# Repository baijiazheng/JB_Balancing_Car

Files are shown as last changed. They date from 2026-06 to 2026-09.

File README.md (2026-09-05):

# JB_Balancing_Car

> A two-wheeled self-balancing robot built around the self-designed JB_board.

## 📖 Project Overview

**JB_Balancing_Car** is a two-wheeled self-balancing robot developed from scratch.

The project combines:

- IMU
- DC geared motors
- Quadrature encoders
- Motor driver
- Real-time control
- PD control
- Velocity-loop architecture
- Timer-based task scheduling
- A self-designed control board — **JB_board**

The project was developed as a practical study of the complete robotics control chain:

```text
Sensor
  ↓
State Estimation
  ↓
Control
  ↓
Motor Output
  ↓
Mechanical Motion
  ↓
Sensor Feedback
```

---

## 🎯 Project Goals

The main objectives were:

- Build a two-wheeled self-balancing robot.
- Design and use a custom control board.
- Integrate an MPU6050 IMU.
- Control two DC motors.
- Acquire encoder feedback.
- Implement a real-time upright controller.
- Explore a cascaded velocity-control architecture.
- Practice hardware/software co-design.
- Develop systematic hardware debugging skills.

---

## 🧩 System Architecture

```text
                 ┌──────────────┐
                 │   MPU6050    │
                 │     IMU      │
                 └──────┬───────┘
                        │
                        ▼
                 ┌──────────────┐
                 │ State        │
                 │ Estimation   │
                 └──────┬───────┘
                        │
                        ▼
                 ┌──────────────┐
                 │ Upright PD   │
                 │ Controller   │
                 └──────┬───────┘
                        │
                        ▼
                 ┌──────────────┐
                 │ Motor Driver │
                 └──────┬───────┘
                        │
                 ┌──────┴──────┐
                 ▼             ▼
              Motor L       Motor R
                 │             │
                 ▼             ▼
             Encoder L     Encoder R
                 │             │
                 └──────┬──────┘
                        ▼
                    Feedback
```

---

## 🔧 Hardware

### Main Components

- **JB_board** — custom control board
- MPU6050 — 6-axis IMU
- Two DC geared motors
- Quadrature encoders — AB-phase feedback
- Motor driver
- 2S LiPo battery
- Two-wheel mechanical chassis

---

## 💻 Software Architecture

The control system uses periodic execution based on hardware timers.

The basic structure is:

```text
Timer
  ↓
Interrupt
  ↓
Set Control Flag
  ↓
Main Loop
  ↓
Read Sensors
  ↓
Calculate Control
  ↓
Output Motor PWM
```

The timer interrupt is kept lightweight, while the main loop performs sensor processing and control calculations.

---

## ⚙️ Upright Control

The primary controller is a PD controller.

```text
Angle Error
     ↓
     P
     +
Angular Velocity
     ↓
     D
     ↓
 Motor PWM
```

The proportional term provides the main restoring action.

The derivative term provides damping and helps reduce oscillation.

---

## 🔄 Velocity Loop

The project was extended toward a cascaded control architecture:

```text
Target Speed
     ↓
Velocity PI Controller
     ↓
Target Angle
     ↓
Upright PD Controller
     ↓
Motor PWM
```

This separates two control objectives:

- **Upright loop** — keeps the robot balanced.
- **Velocity loop** — controls the robot's movement speed.

---

## ⏱️ Real-Time Control

Timer-based scheduling is used to create periodic control tasks.

The basic concept is:

```text
Hardware Timer
      ↓
ISR
      ↓
Flag
      ↓
Main Loop
      ↓
Control Task
```

ISR (中断服务程序) is used to respond to timer events and set the corresponding flag.

The main loop then performs the actual control work.

This approach avoids placing large amounts of computation inside the interrupt routine.

---

## 🔄 Encoder Development

The encoder subsystem became an important part of the project.

The project experimented with:

- External interrupt-based detection
- Timer-based polling
- A/B phase direction detection
- Encoder count accumulation
- Speed feedback

The basic quadrature encoder concept is:

```text
A Phase
   +
B Phase
   ↓
Pulse + Direction
```

The system detects an A-phase transition and checks the B-phase state to determine the direction of rotation.

---

## ⚠️ Hardware Debugging

One of the most important problems encountered during development was encoder instability.

The encoder behaved normally when the motors were not driven.

After the motors were driven, the encoder signals became unreliable.

The debugging process involved:

- Pull-up resistors
- Filter capacitors
- Signal wiring
- Encoder input levels
- Timer polling
- Interrupt detection
- PCB traces
- Motor current
- Electromagnetic interference

The final investigation showed that the physical PCB layout was an important part of the problem.

Motor-related current switching introduced interference into nearby encoder signal traces.

This led to an important engineering lesson:

> **A digital signal is still a physical electrical signal.**

The MCU does not see an abstract `HIGH` or `LOW`.

It sees a real voltage waveform affected by:

- Current switching
- Ground noise
- Electromagnetic coupling
- PCB routing
- Signal integrity
- Wiring

---

## 🧠 Major Engineering Lessons

### 1. Software cannot always fix a hardware problem

If the physical signal is already corrupted, changing the decoding algorithm may not solve the root cause.

```text
Bad Physical Signal
        ↓
Better Algorithm
        ↓
Still Unreliable
```

The debugging process should therefore move from:

```text
Physical Layer
      ↓
Electrical Signal
      ↓
MCU Input
      ↓
Software
```

---

### 2. High-current and low-level signals require different treatment

The motor power path and encoder/IMU signal path have very different electrical characteristics.

```text
Motor
 ↓
Large Current
 ↓
Fast Switching
```

while:

```text
Encoder / IMU
 ↓
Low-level Signal
 ↓
Sensitive to Noise
```

PCB routing, grounding, filtering, and signal separation therefore become critical.

---

### 3. Change one variable at a time

The project also reinforced a fundamental debugging rule:

> **Change one variable at a time.**

Examples include:

- Removing motor drive
- Changing encoder connections
- Swapping left/right channels
- Testing different pull-up resistors
- Adding filtering
- Cutting PCB traces
- Using external wires
- Comparing different decoding methods

This makes it possible to distinguish correlation from causation.

---

## 🏁 Project Result

The V1 system achieved the following milestones:

- Custom control board designed and used
- MPU6050 integration
- Motor control
- Upright PD control
- Timer-based control architecture
- Encoder signal acquisition experiments
- Initial velocity-loop architecture
- Real-world hardware debugging

The V1 PCB design also exposed hardware limitations that prevented the encoder subsystem from reaching the reliability required for further closed-loop development.

Instead of endlessly modifying V1, the hardware was therefore frozen and the lessons were carried forward into the next board revision.

---

## 🛠️ JB_board V2 Direction

The next hardware revision will focus on electrical reliability.

Planned improvements include:

### Power Layout

Separate:

```text
High-current motor power
```

from:

```text
Low-level sensor signals
```

### Signal Routing

Improve:

- Encoder routing
- Grounding
- Signal separation
- Filtering
- Pull-up configuration

### Hardware Reliability

The next revision will prioritize:

```text
Reliable Electrical Signal
        ↓
Reliable Sensor Data
        ↓
Reliable Control
```

before further control optimization.

---

## 📚 What This Project Represents

JB_Balancing_Car represents my first serious attempt to understand a robot as a complete system.

```text
Mechanical System
       +
Electrical System
       +
Embedded Firmware
       +
Control Theory
       +
Real-Time System
       +
Debugging
```

The most valuable result of V1 was not simply whether the robot could stand.

It was learning how failures propagate through a real robotic system and how to trace those failures back to their physical root cause.

---

## 🚀 Future Development

Future development will continue through a new hardware revision:

```text
JB_board V2
      ↓
Reliable Encoder
      ↓
Velocity Loop
      ↓
Cascaded Control
      ↓
Parameter Tuning
      ↓
More Advanced Robot Control
```

The V1 repository will remain as a record of the first hardware and control iteration.

---

## 📌 Project Status

**V1.0 — Frozen**

The V1 hardware is considered a completed experimental iteration.

Future development will be transferred to the next hardware revision.

---

## 👤 Author

**JB**

Robotics / Embedded Systems / Control

GitHub: `baijiazheng`

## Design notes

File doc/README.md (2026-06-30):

# JB_Balancing_Car
This is a two-wheeled self-balancing car that operates on a self-designed board——JB_board.

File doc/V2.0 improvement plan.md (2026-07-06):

电源部分

★★★★★

AMS1117更换为Buck DC-DC。

提高效率。

提升抗瞬态能力。

电机驱动

★★★★☆

继续使用TB6612。

若以后升级电机：

建议使用：

DRV8874
DRV8876
BTS7960
电源保护

★★★★★

取消0805小规格PPTC。

改用：

Mini Blade汽车保险丝。

PCB布局

★★★★☆

进一步分离：

动力区

控制区

减小地回流影响。

调试接口

★★★★★

所有重要信号全部增加Test Point。

电源储能

★★★★☆

TB6612 VM旁增加：

1000µF以上低ESR电解。

提升启动瞬态能力。

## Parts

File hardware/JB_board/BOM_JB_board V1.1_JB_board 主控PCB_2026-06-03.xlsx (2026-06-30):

No. | Quantity | Comment | Designator | Footprint | Value | Manufacturer Part | Manufacturer | Supplier Part | Supplier
1 | 1 | 470uF | C1 | CAP-TH_BD6.3-P2.50-D0.5-FD | 470uF | GR1C471M0611 | ROQANG(容强) | C2873966 | LCSC
2 | 15 | 100nF | C2,C5,C6,C7,C8,C9,C10,C11,C12,C13,C14,C15,C16,C18,C20 | C0805 | 100nF | FCC0805B104K500DT | FOJAN(富捷) | C5137467 | LCSC
3 | 2 | 10uF | C3,C17 | C0805 | 10uF | CGA0805X5R106K250MT | HRE(芯声) | C6119887 | LCSC
4 | 1 | 22uF | C4 | CASE-A_3216 | 22uF | TAJA226K010RNJ | Kyocera AVX | C11366 | LCSC
5 | 1 | SH-XH2.54-2PWZ | CN1 | CONN-TH_SH-XH2.54-2PWZ |  | SH-XH2.54-2PWZ | SHOU HAN(首韩) | C42372642 | LCSC
6 | 2 | HX-PH2.0-4PZZ | CN2,CN3 | CONN-TH_HX-PH2.0-4PZZ |  | HX-PH2.0-4PZZ | hanxia(韩下) | C48641619 | LCSC
7 | 2 | HX002069 | CN4,CN5 | CONN-TH_2P-P2.00-H |  | HX002069 | hanxia(韩下) | C22387095 | LCSC
8 | 1 | SMBJ5.0A | D1 | SMB_L4.3-W3.6-LS5.3-RD |  | SMBJ5.0A | MSKSEMI(美森科) | C5331094 | LCSC
9 | 1 | SMD0805-100-12 | F1 | R0805 |  | SMD0805-100-12 | R+O(宏嘉诚) | C46640991 | LCSC
10 | 1 | PM254V-11-06-H85 | H1 | HDR-TH_6P-P2.54-V-F |  | PM254V-11-06-H85 | XFCN(兴飞) | C2832269 | LCSC
11 | 4 | HC-PM254-5.0H-1x4PZ-02A | H2,H3,H4,H5 | HDR-TH_4P-P2.54-V-F |  | HC-PM254-5.0H-1x4PZ-02A | HC(虹成电子) | C42163122 | LCSC
12 | 8 | PZ254V-11-02P | H6,H7,H8,H9,H10,H11,H12,H13 | HDR-TH_2P-P2.54-V-M |  | PZ254V-11-02P | XFCN(兴飞) | C492401 | LCSC
13 | 1 | XL-2012SURC | LED1 | LED0805-RD_RED |  | XL-2012SURC | XINGLIGHT(成兴光) | C965812 | LCSC
14 | 2 | 2kΩ | R1,R5 | R0805 | 2kΩ | FRC0805J202 TS | FOJAN(富捷) | C2907315 | LCSC
15 | 7 | 10kΩ | R2,R3,R20,R21,R26,R28,R30 | R0805 | 10kΩ | FRC0805J103TS | FOJAN(富捷) | C2930231 | LCSC
16 | 1 | 1kΩ | R4 | R0805 | 1kΩ | FRC0805J102 TS | FOJAN(富捷) | C2907295 | LCSC
17 | 8 | 0Ω | R6,R7,R8,R9,R10,R11,R12,R13 | R0805 | 0Ω | 0805W8F0000T5E | UNI-ROYAL(厚声) | C17477 | LCSC
18 | 8 | 330Ω | R14,R15,R16,R17,R18,R19,R27,R29 | R0805 | 330Ω | 0805W8F3300T5E | UNI-ROYAL(厚声) | C17630 | LCSC
19 | 4 | M3螺丝 | SCREW1,SCREW2,SCREW3,SCREW4 | M3螺丝
20 | 1 | 5.8 ZSGT | SW1 | SW-TH_5.8ZSGT |  | 5.8 ZSGT | SHOU HAN(首韩) | C2681587 | LCSC
21 | 2 | AMS1117-5.0 | U1,U8 | SOT-223-4_L6.5-W3.5-P2.30-LS7.0-BR |  | AMS1117-5.0 | HXY MOSFET(华轩阳电子) | C5345984 | LCSC
22 | 3 | PM2.54-1X8PM-H85 | U2,U3,U4 | HDR-TH_8P-P2.54-V-F |  | PM2.54-1X8PM-H85 | JXTCONN(聚兴泰) | C42431840 | LCSC
23 | 1 | HC-PM254-8.5H-1x3PZ-02A | U5 | HDR-TH_3P-P2.54-V-F |  | HC-PM254-8.5H-1x3PZ-02A | HC(虹成电子) | C22373889 | LCSC
24 | 2 | 315-99-120-41-003000 | U6,U7 | HDR-TH_20P-P2.54-V-F-2 |  | 315-99-120-41-003000 | Mill-Max Mfg. Corp. | C6803796 | LCSC
25 | 2 | 6N137S1(TA) | U9,U14 | SMD-8_L9.8-W6.6-P2.54-LS10.3-BL |  | 6N137S1(TA) | EVERLIGHT(亿光) | C110020 | LCSC
26 | 4 | PC817C | U10,U11,U15,U16 | OPTO-SMD-4_L4.6-W6.5-P2.54-LS10.3-TL |  | PC817C | GOODWORK(固得沃克) | C3025164 | LCSC

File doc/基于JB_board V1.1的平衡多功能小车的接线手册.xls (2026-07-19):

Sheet: 模块BOM表
基于JB_board的平衡多功能小车的模块BOM清单
序号 | 名称 | 数量 | 备注
1 | Arduino mega 2560 | 1
2 | TB6612 驱动板 | 1 | STBY引脚直接接到+5V上
3 | 八路循迹模块 | 1
4 | 0.96英寸OLED显示屏 | 1 | OLED默认地址是0x3C
5 | MPU6050 三维角度传感器 | 1 | MPU6050默认地址是0x68
6 | HM-10 蓝牙4.0模块 | 1 | USB 下载程序（需要拔掉 D14/D15 或断开蓝牙电源）
7 | 红外遥控器 | 1
8 | 6V GA25-370带霍尔编码器电机 | 2 | 基础脉冲11PPR
9 | HC_SR04 超声波模块 | 1
10 | PCF8574 I2C扩展器 | 1 | 默认地址就是0x20，将A0、A1、A2接负极即可

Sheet: 元件BOM表
基于JB_board的平衡多功能小车的元件BOM表
序号 | 元件名称 | 数量 | 封装 | 备注
1 | VS1838 红外接收管 | 1 | SIP-3（2.54mm）
2 | 稳压器 AMS1117-5.0 5V 1A 18V | 1 | SOT-223 | 7.4V降压成5V
3 | 贴片电容 0.1μF (100nF) ±10% 50V | 15 | 0805 | 输入端滤波、每个IC电源引脚的退耦
4 | 电解电容 470uF ±20% 16V | 1 | 插件,D6.3xL11mm | 电机启动电流尖峰吸收
5 | TVS保护管 SMBJ5.0A 5V截止 峰值脉冲电流：65.22A@10/1000us | 1 | SMB（DO-214AA） | 用在5V总线上
6 | 5.8*5.8有头/高头 带锁/自锁开关 泡泡机开关 | 1 | 插件（间距2*4.5mm） | 总电源开关
7 | 肖特基二极管 SS34 电压:40V 电流:3A | 1 | SMA(DO-214AC) | 用于防反接保护
8 | 排母 1x40P 2.54mm排母 | 6 |  | Mega 2560 PRO堆叠 + 所有外设接口
9 | 10kΩ ±5% 125mW 厚膜电阻 | 10 | 0805 | 用作I2C上拉电阻和HM-10的BRK下拉
10 | 1kΩ/2kΩ ±5% 125mW 厚膜电阻 | 各5 | 0805
11 | XH2.54-2P弯针连接器 | 1 | 弯插,P=2.5mm | JST电池接口
12 | 10uF ±10% 25V电容 | 1 | 0805 | AMS1117输入端需要
13 | 22μF 10V 钽电容 A型 | 1 | CASE-A-3216-18(mm) | AMS1117输出端需要
14 | 发光二极管/LED / 0805红贴片式发光二极管 | 1 | 0805 | 显示电源接通情况
15 | 贴片电容(MLCC) / 100nF | 15 | 0805 | 滤波
16 | 0Ω ±1% 125mW 厚膜电阻 | 10 | 0805 | 无破坏的测量点
17 | 2Pin排针 | 10 | 插件（间距2*4.5mm） | 隔离和调试
18 | 自恢复保险丝 12V 1A | 1 | 0805 | 短路，保险丝自动断开，故障排除后自动恢复
19 | 短路帽/跳线帽 2.54mm 开顶式 | 10 | P=2.54mm | 做模块开关
20 | 排针 1x2P 间距:2.54mm 方针 直插 | 10 | 插件,P=2.54mm
21 | 胶壳端子 PH 2.0mm 压接簧片 压线端子 | 5 | - | 霍尔电机接线端子
22 | 胶壳(线对板/线对线) 2.0-4P胶壳 | 2 | P=2mm
23 | 胶壳(线对板/线对线) 2.0-2P胶壳 | 2 | P=2mm
24 | 线对板针座 1x4P 间距:2mm 直插 | 2 | 插件,P=2mm
25 | 线对板针座 1x2P 间距:2mm 弯插 | 2 | 弯插,P=2mm
26 | 逻辑输出光耦6N137S1 DC输入 1通道 隔离电压(rms):5000V | 2 | SOP-8-2.54mm | 控制和电机驱动模块光电隔离
27 | 贴片电阻 220Ω ±1% 125mW | 6 | 0805
28 | 晶体管输出光耦 PC817C | 4 | SMD-4P

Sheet: IO表
基于JB_board的平衡多功能小车的IO表
序号 | 外设名称 | 所需接口数 | 计划分配的接口
1 | TB6612（用光耦光电隔离） | 6 | D4、D5、D8、D6、D7、D9
2 | 八路循迹模块（通过PCF8574） | 2 | D20 (SDA)、D21 (SCL)
3 | 6V GA25-370带霍尔编码器电机（左右两个） | 4 | D2、D3、D22、D23
4 | HC_SR04 超声波模块 | 2 | D18 (Echo), D11 (Trig)
5 | MPU6050 三维角度传感器 | 1 | INT D19、D20 (SDA)、D21 (SCL)
6 | HM-10蓝牙4.0模块 | 2 | D14、D15
7 | VS1838 红外接收管 | 1 | D10
8 | 0.96英寸OLED显示屏 | 2 | D20 (SDA)、D21 (SCL)

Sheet: 电容功能一览
电容功能一览
编号 | 名称 | 备注
1 | C1 470μF | 主要服务TB6612，吸收电机启动电流尖峰
2 | C2 10μF | 中频滤波，靠近AMS1117 Vin脚
3 | C3 0.1μF | 高频去耦，紧贴AMS1117 Vin脚，越小靠得更近一些
4 | C4 22μF钽电容 | AMS1117输出端稳定环路，防止振荡
5

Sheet: MEGA 2560的引脚对应
MEGA 2560的引脚对应
引脚 | 所接元件部分 | 备注
D0 (RX0) | USB调试串口（不接外设）
D1 (TX0) | USB调试串口（不接外设）
D2 (INT0) | 左霍尔传感器接口A
D3 (INT1) | 右霍尔传感器接口A
D4 | 接PC817光电隔离 TB6612 AIN1 | A为左、B为右
D5 | 接PC817光电隔离 TB6612 AIN2
D6 | 接PC817光电隔离 TB6612 BIN1
D7 | 接PC817光电隔离 TB6612 BIN2
D8 (PWM) | 接6N137光电隔离 TB6612 PWMA
D9 (PWM) | 接6N137光电隔离 TB6612 PWMB
D10 | VS1838红外接收管OUT
D11 | 超声波模块 Tring
D14 (TX3) | HM-10 RXD
D15 (RX3) | HM-10 TXD
D18 (INT5) | 超声波模块 Echo | 使用外部中断，禁止使用Serial1
D19 (INT4) | MPU6050 INT | 使用外部中断，禁止使用Serial1
D20 (SDA, INT3) | I2C总线SDA（MPU6050 + OLED + PCF8574）
D21 (SCL, INT2) | I2C总线SCL（MPU6050 + OLED + PCF8574）
D22 | 左霍尔传感器接口B
D23 | 右霍尔传感器接口B
D24 | HM-10 STATE引脚 | 状态指示
D25 | HM-10 BRK引脚 | 断开连接

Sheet: 原理图网络标签表
原理图网络标签表
编号 | 网络标签名 | 电压/类型 | 起点 | 终点 | 备注
1 | BAT+ | 7.4V | JST电池接口1脚 | 自锁开关输入、TB6612 VM | 电池正极
2 | +5V | 5V | AMS1117 VOUT | Mega 5V、TB6612 VCC、各模块VCC | 逻辑电源轨
3 | GND | 0 | 全板所有GND引脚 | 全板共地，铺铜 | 共地
4 | I2C_SDA | 5V | Mega D20 | MPU6050 SDA、OLED SDA、PCF8574 SDA | I2C总线需上拉10kΩ
5 | SW_OUT | 7.4V | 开关接口1 | 稳压模块Vin、滤波电容 | 开关控制总电源
6 | LEFT_HALL | 5V | D2 | 左霍尔信号接口A
7 | RIGHT_HALL | 5V | D3 | 右霍尔信号接口A
8 | IR_OUT | 5V | D10 | VS1838红外接收管OUT
9 | TRIG | 5V | D11 | 超声波模块 Tring
10 | BT_RXD | 5V | D14 | HM-10 RXD | D14是TX3，接HM-10的RXD，所以标签是BT_RXD
11 | BT_TXD | 5V | D15 | HM-10 TXD | D15是RX3，接HM-10的TXD，所以标签是BT_TXD
12 | ECHO | 5V | D18 | 超声波模块 Echo
13 | MPU_INT | 5V | D19 | MPU6050 INT
14 | I2C_SDA | 5V | D20 | I2C总线SDA
15 | I2C_SCL | 5V | D21 | I2C总线SCL
16 | LEFT_HALLD | 5V | D22 | 左霍尔传感器接口B
17 | RIGHT_HALLD | 5V | D23 | 右霍尔传感器接口B
18 | LEFT_AO1 |  | TB6612 AO1 | 左霍尔传感器M+
19 | LEFT_AO2 |  | TB6612 AO2 | 左霍尔传感器M-
20 | RIGHT_BO1 |  | TB6612 BO1 | 右霍尔传感器M+
21 | RIGHT_BO2 |  | TB6612 BO2 | 右霍尔传感器M-
22 | BT_STATE |  | D24 | HM-10 STATE引脚
23 | BT_BRK |  | D25 | HM-10 BRK引脚
24 | BT_RXD1 |  | 分压电路末 | HM-10 RXD引脚 | 最终以 1kΩ + 2kΩ 分压分压后3.3V接地的网络标签
25 | STBY | 5V | TB6612 STBY | +5V总线 | STBY引脚直接接到+5V上
26 | +5V_DRV |  | 电机驱动模块的5V电压 | TB6612 VCC，STBY | 用于光电隔离
27 | GND_DRV |  | 电机驱动模块的接地 |  | 光电隔离地
28 | D4 |  | MEGA2560 D4 | LEFT_IN1
29 | D5 |  | MEGA2560 D5 | LEFT_IN2
30 | D6 |  | MEGA2560 D6 | RIGHT_IN1
31 | D7 |  | MEGA2560 D7 | RIGHT_IN2
32 | D8 |  | MEGA2560 D8 | LEFT_PWM
33 | D9 |  | MEGA2560 D9 | RIGHT_PWM
34 | LEFT_IN1 | 5V | LEFT_IN1 | TB6612 AIN1 | A为左、B为右
35 | LEFT_IN2 | 5V | LEFT_IN2 | TB6612 AIN2
36 | RIGHT_IN1 | 5V | RIGHT_IN1 | TB6612 BIN1
37 | RIGHT_IN2 | 5V | RIGHT_IN2 | TB6612 BIN2
38 | LEFT_PWM | 5V | LEFT_PWM | TB6612 PWMA
39 | RIGHT_PWM | 5V | RIGHT_PWM | TB6612 PWMB

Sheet: 放外设接口排母
放外设接口排母
序号 | 外设名 | 引脚定义
1 | TB6612接口（排母，8脚*2） | VM、VCC(+5V)、GND、LEFT_IN1、LEFT_IN2、LEFT_PWM、STBY
2 |  | LEFT_HALL、RIGHT_HALL、RIGHT_IN1、RIGHT_IN2、RIGHT_PWM
3 | HM-10蓝牙接口（排母，4脚） | VCC(+5V)、GND、BT_TXD、BT_RXD、STATE、BRK
4 | HC_SR04 超声波接口（排母，4脚） | VCC(+5V)、GND、TRIG、ECHO
5 | MPU6050接口（排母，8脚） | VCC(+5V)、GND、I2C_SDA、I2C_SCL、MPU_INT
6 | OLED接口（排母，4脚） | VCC(+5V)、GND、I2C_SDA、I2C_SCL
7 | PCF8574/八路循迹接口（排母，4脚） | VCC(+5V)、GND、I2C_SDA、I2C_SCL
8 | VS1838红外接收管接口（排母，3脚） | VCC(+5V)、GND、IR_OUT
9 | EXT接口（排母，4脚） | VCC(+5V)、GND、I2C_SDA、I2C_SCL

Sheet: 焊接顺序优先级清单
焊接顺序优先级清单
焊接阶段 | 序号 | 焊接内容 | 核心操作要点 | 注意事项
第一阶段：电源核心区（优先级最高，必须最先焊） | 1 | 电池输入接口（BAT+、GND） | 先焊电池座 / 接线端子，确保正负极丝印与 PCB 一致 | 绝对不能焊反正负极，后续所有电源都从这里取电
 | 2 | 自锁开关、自恢复保险丝 | 开关焊在 BAT + 路径上，保险丝串联在 BAT + 正极 | 保险丝不要焊反，确保电流从电池正极先过保险丝、再过开关
 | 3 | 防反接肖特基二极管（SS34） | 阳极（有横线端）接开关输出，阴极接 AMS1117 输入端 | 二极管方向绝对不能焊反，焊反会直接短路烧电池
 | 4 | AMS1117-5.0 稳压芯片 | 1 脚 Vin 接 7.4V 输入，2 脚 GND 接地，3 脚 Vout 接 + 5V 总线 | 芯片贴紧 PCB，引脚不要虚焊，确保散热焊盘接地良好
 | 5 | 电源滤波电容 | 1. AMS1117 输入侧：10μF 电解 + 0.1μF 贴片并联 | 电解电容正负极必须与 PCB 丝印一致，贴片电容无正负极 | 电容必须紧贴芯片引脚，越近滤波效果越好，不要长走线
 |  |  | 2. AMS1117 输出侧：22μF 钽电容 + 0.1μF 贴片并联
 |  |  | 3. TB6612 VM 端：470μF 电解电容
 | 6 | 电源指示灯 LED + 限流电阻 | LED 正极接 + 5V，负极接 1kΩ 限流电阻，电阻另一端接地 | 注意 LED 正负极，长脚为正，短脚为负 | 限流电阻必须焊，否则 LED 上电直接烧
第二阶段：主控与基础接口区 | 7 | Arduino Mega2560 排母座 | 先焊 2×20P 排母，确保引脚对齐 PCB 焊盘，无虚焊、连锡 | 排母必须插到底，贴紧 PCB，避免引脚悬空导致接触不良
 | 8 | I2C 总线 10kΩ 上拉电阻 | 电阻一端接 SDA/SCL，另一端接 + 5V，靠近 Mega 排母端 | 两个上拉电阻必须都焊，否则 I2C 设备无法正常通信
 | 9 | 0Ω 调试电阻 / 预留测试点 | 按 PCB 设计焊好 0Ω 电阻，预留测试点可焊上排针 | 0Ω 电阻不要用导线代替，方便后续调试断开电路
第三阶段：电机驱动与编码器接口区 | 10 | 6个光耦 TB6612 电机驱动排母 / 接口 | 先焊 TB6612 的排母，确保 VM、GND、AIN1/AIN2、PWMA 引脚对齐 | VM 引脚必须接 7.4V，VCC 引脚接 + 5V，绝对不能接反
 | 11 | 电机输出接线端子（M+、M-） | 焊好左右电机的 2P 接线端子，正负极与 PCB 丝印一致 | 端子必须焊牢，电机大电流容易导致虚焊发热
 | 12 | 霍尔编码器接口 | 焊好编码器的 4P/6P 接口，VCC 接 + 5V，GND 接地，A/B 相引脚对齐 | 编码器 A/B 相的 10kΩ 上拉电阻必须焊好，避免信号干扰
第四阶段：传感器与外设接口区 | 13 | MPU6050 陀螺仪接口 | 焊好 MPU6050 的排母，VCC 接 + 5V，GND 接地，SDA/SCL/INT 引脚对齐 | INT 引脚必须接 Mega 的中断口，不要焊错引脚
 | 14 | 0.96 寸 OLED、PCF8574 扩展板接口 | 焊好对应的排母，SDA/SCL 并联到 I2C 总线，VCC/GND 对齐 | 确保 I2C 地址无冲突，所有设备的 SDA/SCL 都并联在总线上
 | 15 | HC-SR04 超声波、VS1838 红外接收接口 | 焊好对应的排母，VCC 接 + 5V，GND 接地，TRIG/ECHO/OUT 引脚对齐 | 红外接收的 10kΩ 上拉电阻必须焊好，避免信号误触发
 | 16 | HM-10 蓝牙模块接口 | 焊好蓝牙排母，VCC 接 + 5V，GND 接地，TXD/RXD 交叉连接 | 蓝牙的 STATE/BRK 引脚的 10kΩ 下拉电阻必须焊好，避免浮空误触发
第五阶段：收尾与加固 | 17 | 所有排针 / 排母补焊加固 | 对所有接口的引脚进行补焊，确保无虚焊、连锡 | 重点检查大电流接口（电池、电机），必须焊牢
 | 18 | 热熔胶 / 热缩管加固 | 对电池线、电机线的焊点用热熔胶固定，避免震动松脱 | 热熔胶不要覆盖到其他元件引脚，避免短路

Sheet: 上电前安全检查清单
上电前安全检查清单
检查模块 | 序号 | 检查项 | 操作步骤 | 合格标准 | 风险提示
一、电源回路安全检查（最核心，必过） | 1 | BAT + 与 GND 无短路 | 用万用表通断档，测电池接口的 BAT + 与 GND 之间的通断 | 万用表无蜂鸣，电阻值为无穷大 | 短路会直接烧电池、炸板，绝对不能上电
 | 2 | +5V 与 GND 无短路 | 用万用表通断档，测 AMS1117 输出的 + 5V 与 GND 之间的通断 | 万用表无蜂鸣，电阻值为无穷大 | 短路会烧 AMS1117、Mega 主控、所有传感器
 | 3 | 7.4V 与 + 5V 无短路 | 用万用表通断档，测 BAT+（7.4V）与 + 5V 之间的通断 | 万用表无蜂鸣，电阻值为无穷大 | 7.4V 直接灌入 5V 总线，会烧所有逻辑元件
 | 4 | 防反接二极管方向正确 | 用万用表二极管档，测 SS34 的正向导通、反向截止 | 正向导通压降 0.2-0.3V，反向电阻无穷大 | 二极管焊反会导致电池插反直接短路
 | 5 | 自恢复保险丝通断正常 | 用万用表通断档，测保险丝两端的通断 | 万用表有蜂鸣，电阻值接近 0Ω | 保险丝开路会导致全车无电，焊反 / 虚焊会导致过流无法保护
二、焊接质量与通断检查 | 6 | 所有元件无虚焊、连锡 | 用放大镜肉眼检查所有焊点，重点检查排母、芯片引脚 | 焊点饱满、无虚焊、无连锡、无铜箔翘起 | 虚焊会导致接触不良、功能失效，连锡会直接短路
 | 7 | 所有电源引脚通断正常 | 用万用表通断档，测所有元件的 VCC 引脚到 + 5V 总线、GND 引脚到 GND 总线的通断 | 所有对应引脚都有蜂鸣，电阻值接近 0Ω | 电源引脚开路会导致元件不工作，虚焊会导致上电重启
 | 8 | 电解电容正负极正确 | 肉眼检查所有电解电容的正负极，与 PCB 丝印一致 | 电容正极接高电位，负极接 GND，无焊反 | 电解电容焊反会直接鼓包、爆炸，烧板
三、接口与引脚匹配检查 | 9 | 所有接口正负极正确 | 对照 PCB 丝印，检查所有接口的 VCC/GND 引脚顺序，与外接模块一致 | 所有接口的 VCC 接 + 5V，GND 接地，无反接 | 模块接反会直接烧元件，比如 MPU6050、OLED 接反直接报废
 | 10 | Mega 引脚分配正确 | 对照 IO 规划表，检查所有信号引脚的焊接位置，与 PCB 丝印一致 | 中断口、PWM 口、I2C 口、串口引脚无焊错 | 引脚焊错会导致功能失效，比如编码器接错中断口无法测速
 | 11 | 蓝牙 TXD/RXD 交叉连接 | 检查蓝牙模块的 TXD 接 Mega 的 RXD，蓝牙的 RXD 接 Mega 的 TXD | 交叉连接正确，无直连 | 直连会导致蓝牙无法通信，数据收发失败
四、信号通路与保护元件检查 | 12 | I2C 上拉电阻焊接正确 | 用万用表通断档，测 SDA/SCL 引脚到 + 5V 的通断，经过 10kΩ 电阻 | 电阻两端通断正常，无开路、短路 | 上拉电阻缺失会导致 I2C 设备无法正常通信，信号不稳定
 | 13 | 编码器 / 红外上拉电阻焊接正确 | 检查编码器 A/B 相、红外接收 OUT 引脚的 10kΩ 上拉电阻，一端接引脚，一端接 + 5V | 电阻焊接正确，无开路、短路 | 上拉电阻缺失会导致信号干扰、误触发，编码器测速不准
 | 14 | TVS 保护管焊接正确 | 检查 SMBJ5.0A TVS 管，阴极接 + 5V，阳极接 GND | 焊接方向正确，无反接 | TVS 管焊反会导致 + 5V 与 GND 短路，烧板
五、最终上电前确认 | 15 | 所有外接模块已断开 | 上电前，拔掉所有外接的电机、传感器、蓝牙、OLED 模块 | 只有主控板本身，无任何外接负载 | 避免外接模块故障导致主控板烧损
 | 16 | 电池电压正常 | 用万用表测电池电压，确认是 7.4V 左右，无过放、过充 | 电池电压在 6.5V-8.4V 之间 | 过放电池会导致上电瞬间电压跌落，Mega 重启
 | 17 | 万用表准备就绪 | 准备好万用表，上电后立即测 + 5V 输出电压，确认正常 | 随时可测量，无需断电 | 上电后第一时间确认电压，避免异常电压烧元件

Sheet: 快速故障排查表
快速故障排查表
序号 | 常见异常现象 | 可能原因 | 检查步骤
1 | 蓝牙连不上 | 电压不稳 | 检查 TXD/RXD 是否交叉、分压后电压是否 3.0~3.3V
2 | 蓝牙收到乱码 | 波特率不一致 | 检查 HC-06 与程序 Serial 波特率是否一致
3 | 串口没有任何输出 | 串口号错误 | 检查 Serial、Serial1、Serial2、Serial3 是否对应正确接口
4 | 电机完全不转 | STBY 未拉高 | 测量 STBY 电压是否约5V
5 | 左右轮方向相反 | 左右轮方向相反 | 对调电机两根线，或修改 IN1、IN2 控制逻辑
6 | 编码器计数一直为0 | 中断未进入 | 检查 D2/D3 是否配置为 External Interrupt，确认 ISR 已注册
7 | 编码器方向相反 | AB相判断错误 | 前推轮子应计数增加，后推应减少，否则修改方向判断
8 | MPU6050角度一直漂移 | 未静止校准 | 开机保持静止2~3秒，重新校准零偏
9 | 下载程序失败 | COM口错误 | 检查 PlatformIO 选择的串口是否正确
10 | 编译成功但程序异常 | 修改后未重新上传 | 确认 Upload 成功，而不是仅 Build 成功
⚠ 本表仅记录"可在5分钟内定位和解决"的常见问题。涉及硬件损坏、架构设计缺陷或需要长期跟踪的问题，统一记录到 GitHub Issue。

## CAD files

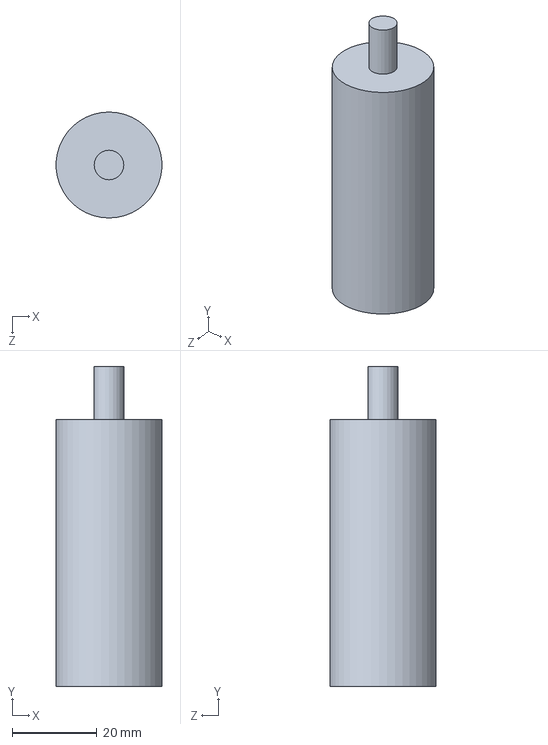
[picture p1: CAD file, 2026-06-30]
hardware/JB_balancecar_V1.1 3D Modeling/JB_balancecar_电机模型.SLDPRT
24.9 x 75.5 x 25.0 mm

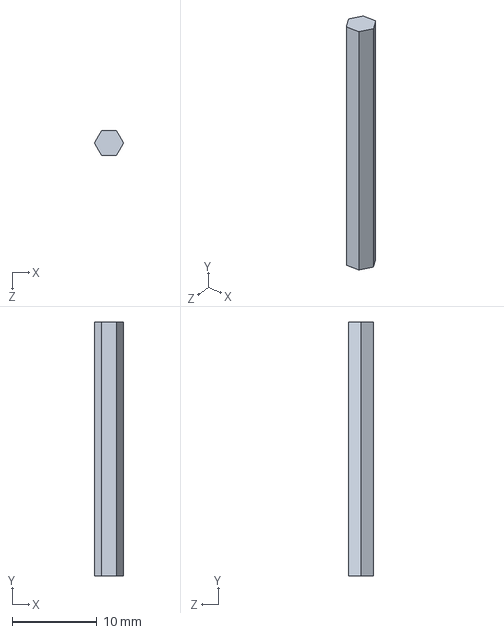
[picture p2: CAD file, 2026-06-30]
hardware/JB_balancecar_V1.1 3D Modeling/JB_balancecar_30六棱铜柱.SLDPRT
3.46 x 30.0 x 3.00 mm

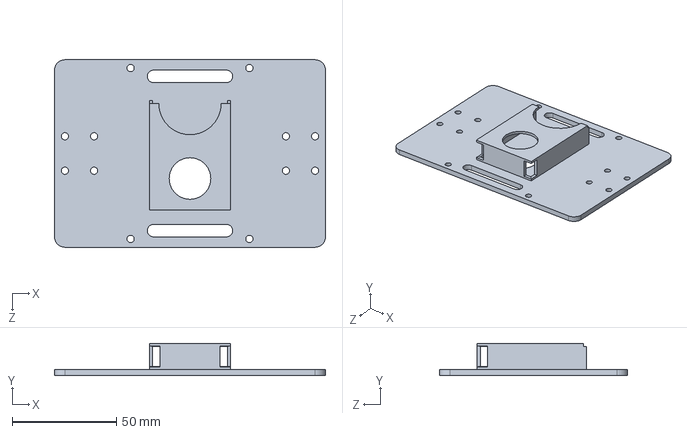
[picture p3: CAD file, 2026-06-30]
hardware/JB_balancecar_V1.1 3D Modeling/JB_balancecar_主框架.SLDPRT
130.0 x 15.5 x 90.0 mm

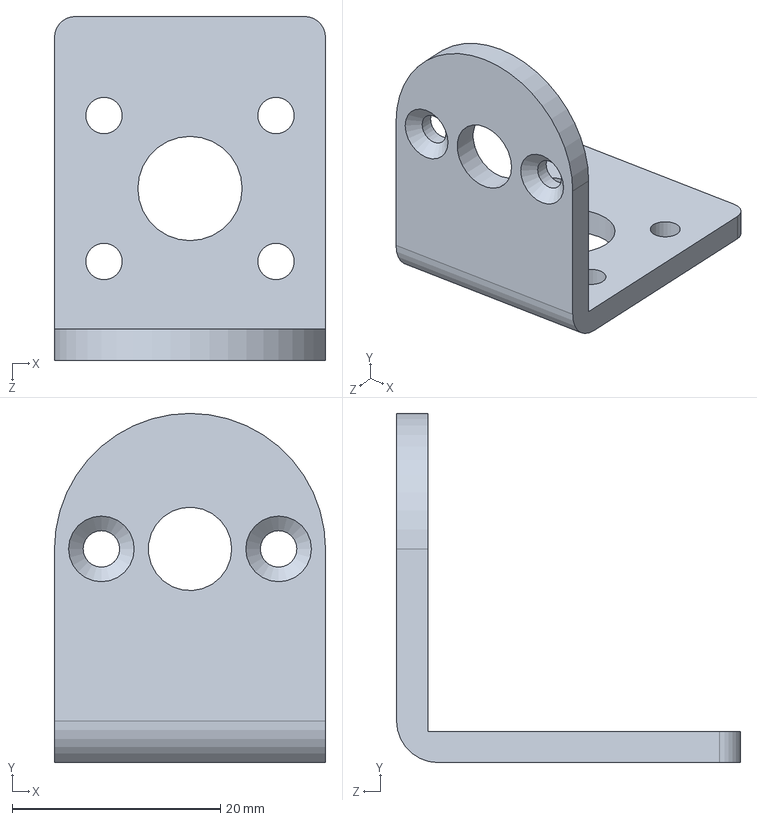
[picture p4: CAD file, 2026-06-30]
hardware/JB_balancecar_V1.1 3D Modeling/JB_balancecar_电机支架.SLDPRT
26.0 x 33.5 x 33.0 mm

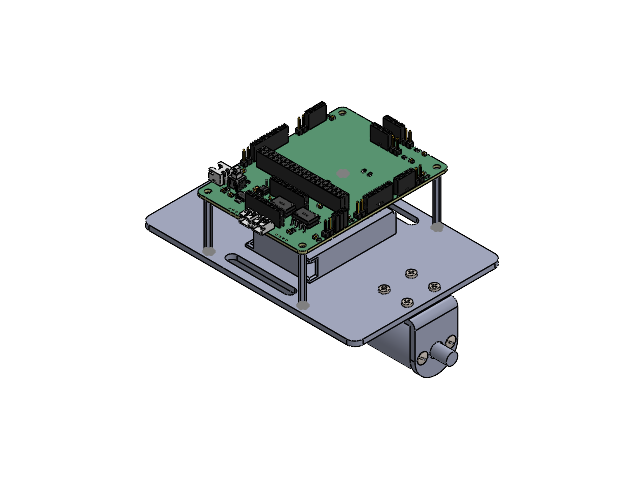
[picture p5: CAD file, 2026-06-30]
hardware/JB_balancecar_V1.1 3D Modeling/JB_balancecar_装配1.1.SLDASM
SW-TH_5.8ZSGT~SW-TH_5.8ZSGT~NAPp.step
R0805~R0805_L2.0-W1.3-H0.6~rMOK.step x 27
HDR-TH_4P-P2.54-V-F~HDR-TH_4P-P2.54-V-F~dq6p.step x 4
CASE-A_3216~CASE-A_3216~v4Qd.step
CONN-TH_SH-XH2.54-2PWZ~CONN-TH_SH-XH2.54-2PWZ~Sl4J.step
C0805~C0805_L2.0-W1.3-H1.3~e9Bd.step x 17
HDR-TH_2P-P2.54-V-M~HDR2.54-M-LI-1X2P~T4wx.step x 8
SMB_L4.3-W3.6-LS5.3-RD~SMB_L4.32-W3.62-LS5.3-RD~sRhQ.step
CONN-TH_2P-P2.00-H~CONN-TH_2P-P2.00-H~YPos.step x 2
OPTO-SMD-4_L4.6-W6.5-P2.54-LS10.3-TL~OPTO-SMD-4_L4.6-W6.5-H3.6-LS10.2-P2.54~ZRMW.step x 4
CAP-TH_BD6.3-P2.50-D0.5-FD~CAP-TH_BD6.3-P2.50-D0.5-FD~njeW.step
HDR-TH_6P-P2.54-V-F~HDR-TH_6P-P2.54-V-F~7zsm.step
HDR-TH_20P-P2.54-V-F-2~HDR-TH_20P-P2.54-V-F-2~DWYS.step x 2
LED0805-RD_RED~LED0805-RD_RED~U96V.step
HDR-TH_8P-P2.54-V-F~HDR-TH_8P-P2.54-V-F~PeWd.step x 3
SMD-8_L9.8-W6.6-P2.54-LS10.3-BL~SMD-8_L9.8-W6.6-H3.8-LS10.3-P2.54~XD9S.step x 2
HDR-TH_3P-P2.54-V-F~HDR2.54-F-LI-1X3P~pnja.step
SOT-223-4_L6.5-W3.5-P2.30-LS7.0-BR~SOT-223-4P_L6.5-W3.5-H1.6-LS7.0-P2.30~ae1e.step x 2
Board~h9fr.step
JB_balancecar_主框架
JB_balancecar_30六棱铜柱 x 4
JB_balancecar_电机模型 x 2
JB_balancecar_电机支架 x 2
GB_FASTENER_SCREWS_CSRHS M3X8-6.35-N x 4
GB_CROSS_SCREWS_TYPE135 M3X8-N x 8

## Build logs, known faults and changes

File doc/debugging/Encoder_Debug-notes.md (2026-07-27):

# Encoder Feedback Corruption Caused by Motor PWM EMI

**Project:** JB_Balancing_Car_V1  
**Module:** Motor Control / Encoder Feedback System  
**Type:** Hardware Debugging Record  
**Date:** 2026-07

---

## 1. Problem Description（问题描述）

During the development of the balancing car velocity control system, abnormal encoder feedback signals were observed when driving the motors.

在加入电机驱动代码后，编码器反馈出现异常：

- Encoder position increased without physical movement.
- Encoder speed showed large values during motor stall.
- Encoder direction became unstable.
- Left and right wheel feedback occasionally showed opposite or random directions.

**Typical abnormal data:**

| Parameter | Value |
|---|---|
| Speed Left | 0 |
| Speed Right | -980 |
| Tick Left | 0 |
| Tick Right | -8607 |

**However:**

- Manual rotation of the wheel produced correct encoder feedback.
- Forward and reverse rotation direction were correctly detected.
- Encoder ISR logic was verified.

> **Conclusion:** The problem was unlikely to originate from encoder decoding software.

---

## 2. Initial Hypothesis（初始猜测）

The possible causes were divided into four categories:

---

### 2.1 Software Issue

**Possible causes:**
- Incorrect interrupt configuration
- Wrong A/B phase decoding
- Counter overflow
- Incorrect direction judgment

**Verification:**
- Manual wheel rotation produced correct direction.
- Encoder ISR counter matched physical movement.

**Conclusion:** ❌ Software logic was not the root cause.

---

### 2.2 Encoder Hardware Failure

**Possible causes:**
- Magnetic encoder damage
- Signal output abnormal
- B phase missing

**Verification:**
- Without motor operation:
  - Encoder A/B signals were stable.
  - Position counting worked normally.

**Conclusion:** ❌ Encoder hardware was functional.

---

### 2.3 Power Supply Problem

Because abnormal behavior appeared during motor operation, battery voltage was checked.

A low battery condition was discovered:

| Item | Value |
|---|---|
| 2S Li-ion battery nominal voltage | 7.4V |
| Actual voltage during debugging | ~4.6V |

**However, after charging:** The problem still existed.

**Conclusion:** ⚠️ Power instability existed, but was not the primary cause.

---

## 3. Key Experimental Observation（关键实验）

A critical relationship was discovered:

| Condition | Result |
|---|---|
| Motor OFF, PWM = 0 | Encoder: Normal |
| Motor ON, PWM output active | Encoder: Incorrect |

> The encoder failure only appeared when the motor driver generated PWM switching.

**This indicated:**
- The encoder signal itself was not wrong.
- The surrounding electromagnetic environment was affecting the signal.

---

## 4. Root Cause Analysis（根因分析）

### Motor PWM Electromagnetic Interference (EMI)

The motor driver generates high-frequency switching signals:

```
TB6612 PWM:
HIGH
 |
 |
LOW
 |
 |
HIGH
```

The rapid current change produces:
- Magnetic field variation
- Electric field coupling
- Ground noise

---

### PCB Layout Problem

The PCB layout had:

```
Motor PWM trace
======================

Encoder signal trace
======================
```

> The high-current switching trace was placed close and parallel to the low-level encoder signal line.

This caused **electromagnetic coupling**.

---

### Signal Corruption Mechanism

**Real signal:**
```
0 -------- 1 -------- 0
```

**Corrupted signal:**
```
0 --1--0--1--0--1
```

The MCU interpreted these noise edges as encoder transitions.

**Therefore:**
- False interrupts occurred.
- Position accumulated incorrectly.
- Speed calculation became meaningless.
- Direction judgment became random.

---

## 5. Verification Experiments（验证实验）

---

### Experiment 1: Motor disconnected

**Result:** Encoder normal

> Confirmed that encoder hardware and software were functional.

---

### Experiment 2: Different PWM levels

**Observation:**

| Motor Power | PWM | Encoder Error |
|---|-----|---|
| Low | Small | Reduced |
| High | Large | Increased |

> This confirmed the relationship between motor switching energy and encoder disturbance.

---

### Experiment 3: Pull-up resistor improvement

Additional pull-up resistors were added:

| Resistor | Result |
|---|---|
| 10kΩ | Signal stability improved |
| 4.7kΩ | Further improvement |

**However:** The issue was not completely solved.

> **Conclusion:** The signal needed stronger noise immunity, but the PCB layout remained the fundamental problem.

---

## 6. Final Solution（最终解决方案）

---

### Immediate Solution

For current prototype:
1. Separate encoder signal routing from motor PWM traces.
2. Improve signal pull-up strength.
3. Add filtering capacitors where necessary.
4. Reduce unnecessary wire length.

---

### PCB V2.0 Design Improvements

#### 1. Separate Power and Signal Areas

**High current section:**
```
Battery
   |
Motor Driver
   |
Motor Output
```

**Low signal section:**
```
Encoder
IMU
Communication
```

---

#### 2. Avoid Parallel Routing

**Bad:**
```
PWM =================
ENC =================
```

**Good:**
```
PWM -------->

    (signal separation)

ENC -------->
```

> If crossing is necessary: **Cross at 90 degrees.**

---

#### 3. Add Motor Noise Suppression

Add capacitor across motor terminals:

```
Motor +
    ||
   100nF
    ||
Motor -
```

**Purpose:** Reduce brush noise and switching disturbance.

---

#### 4. Improve Encoder Signal Design

**Recommended:**
- Stronger pull-up resistor.
- Shorter signal path.
- Ground reference near signal.
- Optional RC filtering.

---

## 7. Engineering Lessons Learned（工程总结）

This debugging process changed the understanding of embedded robotics systems.

**Initially:**
> Incorrect data means incorrect code.

**After debugging:**
> Sensor data is the result of the entire physical system.

---

### The Signal Chain

```
Motor Current
     ↓
Electromagnetic Field
     ↓
PCB Layout
     ↓
Sensor Signal Quality
     ↓
MCU Input
     ↓
Control Algorithm
```

> A software error may actually originate from hardware interaction.

---

## 8. Future Design Principle（未来设计原则）

For next generation robot platforms:

---

### Hardware
- Consider EMC during PCB design.
- Separate high-current and sensitive signal paths.
- Design for signal integrity.

---

### Firmware
- Add sensor diagnostic tools.
- Monitor ISR frequency.
- Detect impossible encoder states.

---

### System Engineering

> A robot is not only code.

**It is an integrated system:**
```
Mechanical
    ↓
Electrical
    ↓
Sensors
    ↓
Firmware
    ↓
Control Algorithm
```

---

## Debug Summary

| Item | Result |
|---|---|
| Encoder software | Normal |
| Encoder hardware | Normal |
| Battery | Contributed but not root cause |
| Motor PWM | Trigger condition |
| Root cause | PWM EMI coupling |
| Final fix | PCB layout improvement |

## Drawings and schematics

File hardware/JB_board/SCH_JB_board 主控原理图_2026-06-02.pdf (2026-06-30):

# HC-PM254-5.0H-1x4PZ-02A 1 1 2 2 3 3 4 4

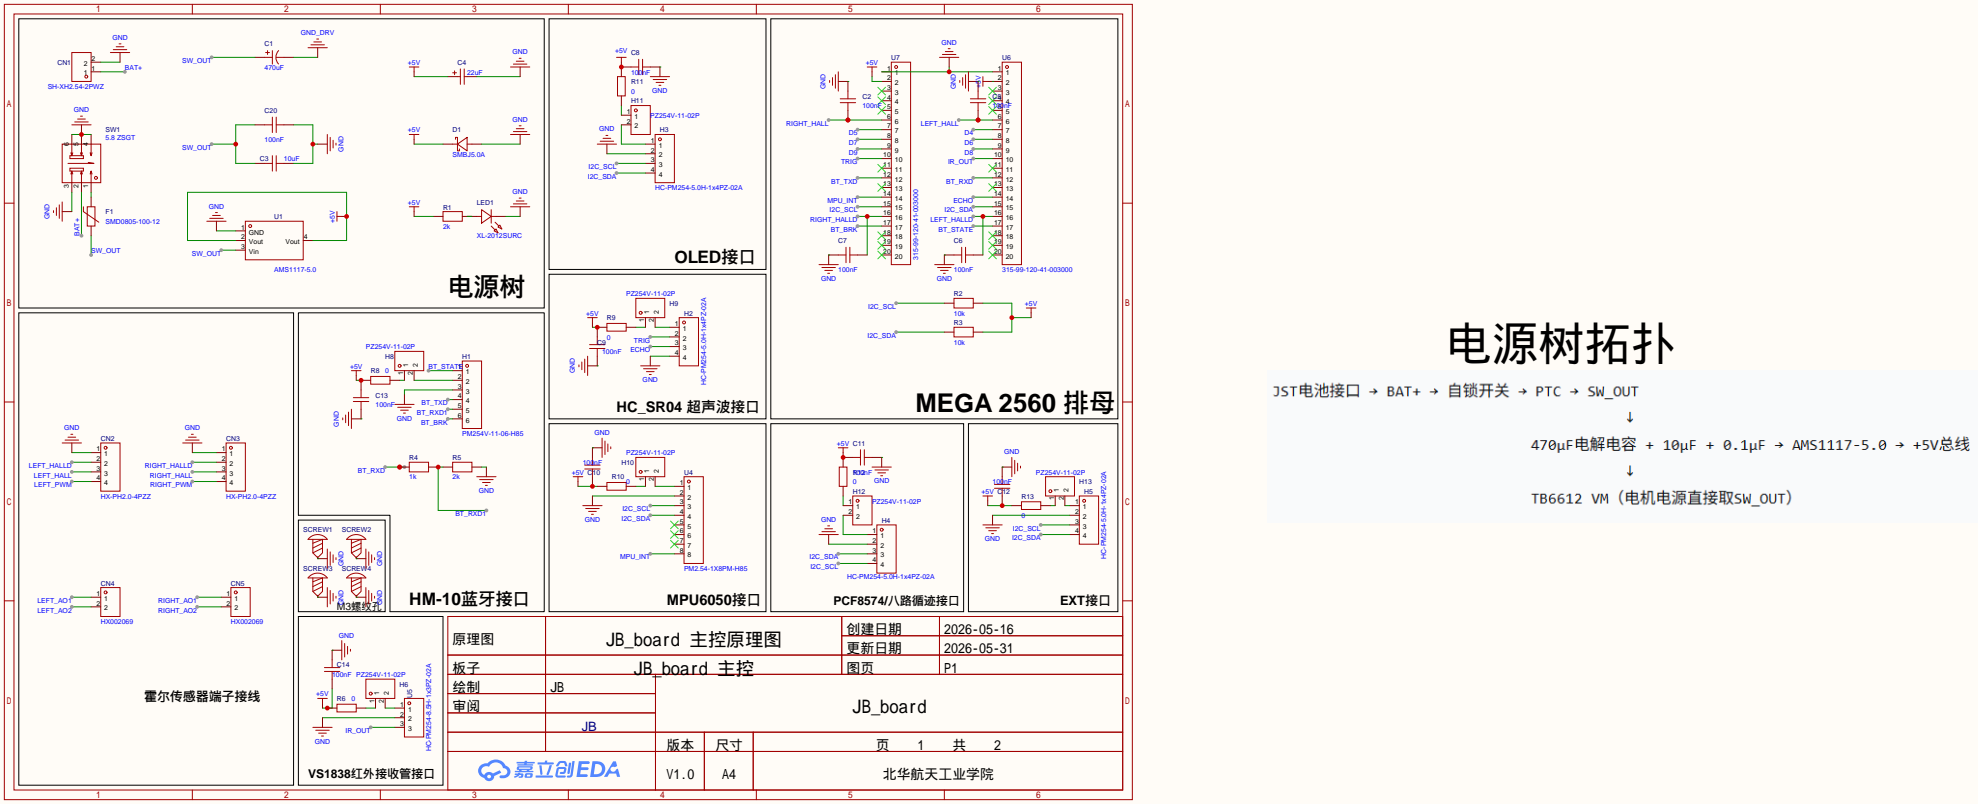
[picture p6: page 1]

原理图 | JB_board 主控原理图 | 创建日期 | 2026-05-16

更新日期 | 2026-05-31

板子 | JB_board 主控 | 图页 | P1
绘制 | JB | JB_board
审阅

V1.0 | A4 | 北华航天工业学院

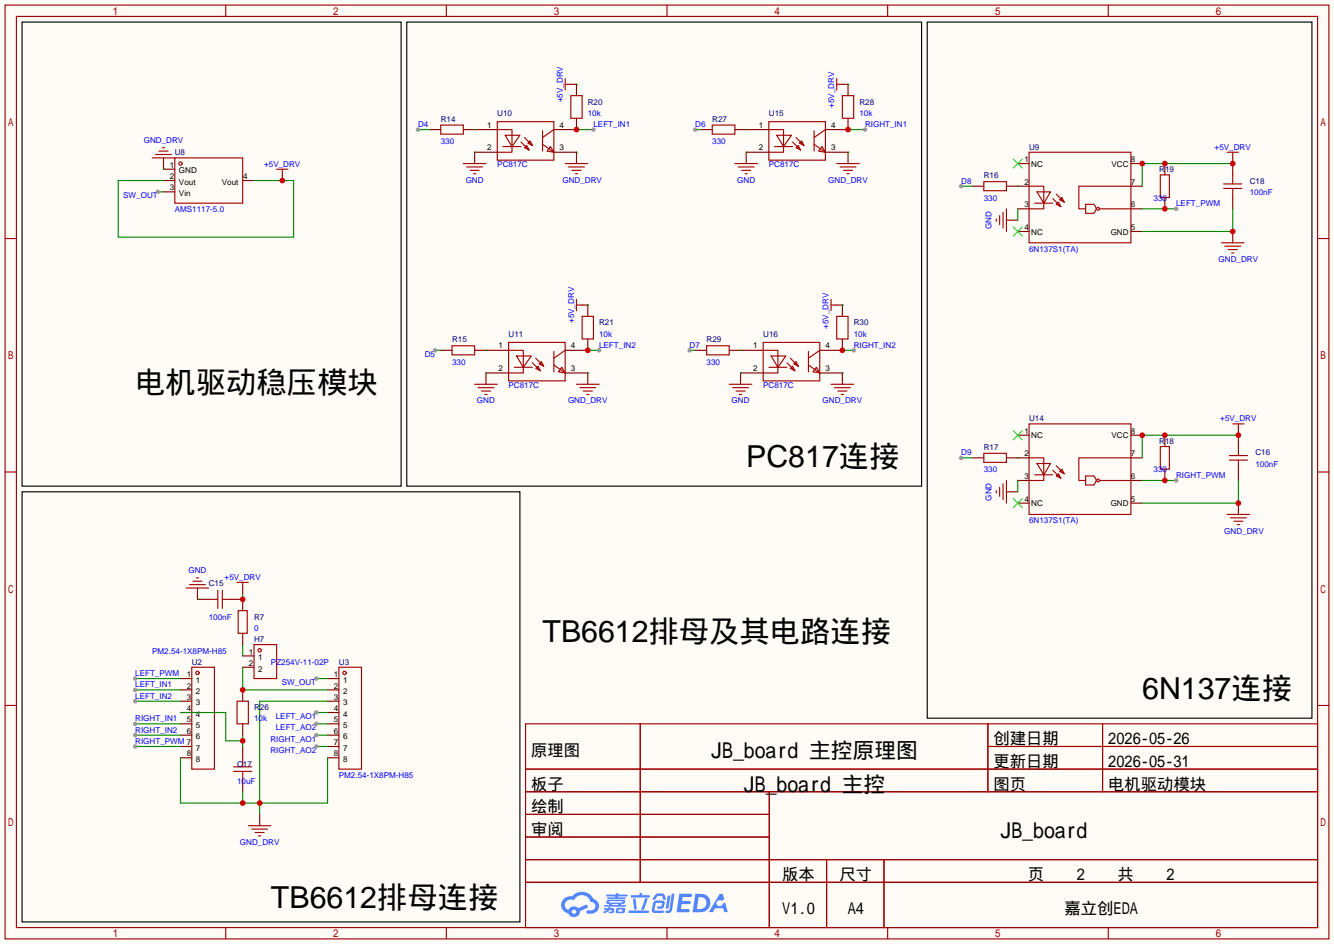
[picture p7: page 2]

原理图 | JB_board 主控原理图 | 创建日期 | 2026-05-26

更新日期 | 2026-05-31

板子 | JB_board 主控 | 图页 | 电机驱动模块
绘制 | | JB_board
审阅

V1.0 | A4 | 嘉立创EDA

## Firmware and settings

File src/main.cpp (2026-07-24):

#include <Arduino.h>
#include "MPU6050.h"
#include "Control.h"
#include "Bluetooth.h"
#include "Timer1.h"
#include "HW_CONFIG.h"
#include "Motor.h"
#include "Encoder.h"
#include "System_Mode.h"
#include "Balance_Mode.h"
#include "Encoder_Test.h"
#include "Motor_Test.h"
#include "Bluetooth_Config.h"

// ================= 主系统入口 =================
void setup() {
    #if SYSTEM_MODE == 1
    Balance_Mode_Init();
    #elif SYSTEM_MODE == 2
    Encoder_Test_Init();
    #elif SYSTEM_MODE == 3
    Motor_Test_Init();
    #elif SYSTEM_MODE == 4
    Telemetry_CONFIG(); 
    #endif
}

// ================== 主循环 ==================
    void loop() {
    #if SYSTEM_MODE == 1
    Balance_Mode_Loop();
    #elif SYSTEM_MODE == 2
    Encoder_Test();
    #elif SYSTEM_MODE == 3
    Motor_Diagnostic_Test();
    #endif
}

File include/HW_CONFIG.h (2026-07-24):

#ifndef HW_CONFIG_H
#define HW_CONFIG_H

#include <Arduino.h>

// ==========================================
// [EN] 0. Hardware Configuration Constants
// [CN] 0. 硬件配置常量
// ==========================================
#define MOTOR_ENCODER_PPR 11
#define GEAR_RATIO 10
#define WHEEL_ENCODER_COUNT 110

// ==========================================
// [EN] 1. Pin Mapping (Physical to Logical)
// [CN] 1. 引脚映射 (物理引脚 -> 逻辑名称)
//  注意：你需要根据你的 PCB 原理图修改以下具体数字！
// ==========================================

// --- Motor Drive (TB6612) Pins ---
constexpr uint8_t PIN_MOTOR_L_PWM = 8;  // 左轮速度控制
constexpr uint8_t PIN_MOTOR_L_IN1 = 4;  // 左轮方向 1
constexpr uint8_t PIN_MOTOR_L_IN2 = 5;  // 左轮方向 2

constexpr uint8_t PIN_MOTOR_R_PWM = 9;  // 右轮速度控制
constexpr uint8_t PIN_MOTOR_R_IN1 = 6;  // 右轮方向 1
constexpr uint8_t PIN_MOTOR_R_IN2 = 7;  // 右轮方向 2

// --- Encoder Pins ---
constexpr uint8_t PIN_ENC_L_A = 2;     // 左编码器 A 相 (必须是外部中断引脚)
constexpr uint8_t PIN_ENC_L_B = 22;     // 左编码器 B 相
constexpr uint8_t PIN_ENC_R_A = 3;     // 右编码器 A 相 (必须是外部中断引脚)
constexpr uint8_t PIN_ENC_R_B = 23;     // 右编码器 B 相



// ==========================================
// [EN] 2. Hardware Initialization Function
// [CN] 2. 硬件初始化函数声明
// ==========================================
void Hardware_Init();

#endif // HW_CONFIG_H

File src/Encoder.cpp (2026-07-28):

#include "HW_CONFIG.h"
#include "Encoder.h"
#include "Bluetooth.h"
#include "Timer3.h"

volatile int32_t encoder_count_L = 0;
volatile int32_t encoder_count_R = 0;
volatile int32_t encoder_delta_L = 0;
volatile int32_t encoder_delta_R = 0;
volatile int32_t encoder_tick_L = 0;
volatile int32_t encoder_tick_R = 0;
volatile int32_t B_HIGH_L_count = 0;
volatile int32_t B_LOW_L_count = 0;
volatile int32_t B_HIGH_R_count = 0;
volatile int32_t B_LOW_R_count = 0;
// [EN] Static counter hidden from global scope (Encapsulation)
// [CN] 隐藏在局部作用域的静态计数器，实现面向对象级别的封装，防止被外部意外篡改
static uint8_t speed_counter = 0;
int32_t speed_car = 0; // [EN] Average speed of the car / [CN] 小车的平均速度
volatile int32_t Isr_L_count = 0;
volatile int32_t Isr_R_count = 0;

volatile uint32_t last_interrupt_time_L = 0;
volatile uint32_t last_interrupt_time_R = 0;
// static uint8_t last_A_L = LOW ;
// static uint8_t last_A_R = LOW ;

// --------------------------------------------------------
// [EN] Interrupt Service Routines (ISR)
// [CN] 中断服务函数：越短越好，绝对不能有 delay 或 Serial.print
// -------------------------------------------------------
void ISR_Encoder_L() {
    ++Isr_L_count;
    
    if((digitalRead(PIN_ENC_L_A) == HIGH)){
        // 当 A 相发生上升沿时，读取 B 相的电平来判断方向
        if(digitalRead(PIN_ENC_L_B) == LOW) { // [EN] If B phase is low, the wheel is moving forward / [CN] 如果 B 相为低电平，说明轮子在正向转动
            // encoder_count_L++;
            encoder_delta_L++;
            // B_LOW_L_count++;
        } else {
            // encoder_count_L--;
            encoder_delta_L--;
            // B_HIGH_L_count++;
        }
    }
}

void ISR_Encoder_R() {
    ++Isr_R_count;

    if (digitalRead(PIN_ENC_R_A) == HIGH){
        if(digitalRead(PIN_ENC_R_B) == LOW) {
            // encoder_count_R--; // 注意：由于电机是对称安装的，左右轮的极性可能相反，后续联调时可能需要把 ++ 和 -- 互换
            encoder_delta_R--;
            // B_LOW_R_count++;
        } else {
            // encoder_count_R++;
            encoder_delta_R++;
            // B_HIGH_R_count++;
        }
    }
}

// --------------------------------------------------------
// [EN] Initialization
// [CN] 中断初始化
// --------------------------------------------------------
void Encoder_Init() {
    // 确保在 hw_config.cpp 中，引脚已经被配置为 INPUT_PULLUP
    
    // 绑定外部中断：指定引脚，指定中断服务函数，指定触发条件 (RISING = 上升沿触发)
    // 必须使用 digitalPinToInterrupt 将物理引脚号转为底层中断号
    attachInterrupt(digitalPinToInterrupt(PIN_ENC_L_A), ISR_Encoder_L, RISING);
    attachInterrupt(digitalPinToInterrupt(PIN_ENC_R_A), ISR_Encoder_R, RISING);
}

// --------------------------------------------------------
// [EN] Speed Readers (Atomic Access)
// [CN] 速度读取函数 (包含原子级防撕裂保护)
// --------------------------------------------------------
// void Get_Timer_ENC(){
//     if (flag_100us){
//         flag_100us = false;

//         //[EN] Read the A in 100us.
//         //[CN] 在100us中读A
        
//         uint8_t current_A_L = digitalRead(PIN_ENC_L_A);
//         if (current_A_L == HIGH && last_A_L == LOW) {
//             ++Timer_L_count;
//             if((PINA & (1 << PA0)) == 0) { // [EN] If B phase is low, the wheel is moving forward / [CN] 如果 B 相为低电平，说明轮子在正向转动
//                 encoder_count_L++;
//                 encoder_delta_L++;
//                 B_LOW_L_count++;
//             } else {
//                 encoder_count_L--;
//                 encoder_delta_L--;
//                 B_HIGH_L_count++;
//             }
//         }
//         last_A_L = current_A_L;

//         uint8_t current_A_R = digitalRead(PIN_ENC_R_A);
//         if (current_A_R == HIGH && last_A_R == LOW){
//             ++Timer_R_count;
//             if((PINA & (1 << PA1)) == 0) {
//                 encoder_count_R--; // 注意：由于电机是对称安装的，左右轮的极性可能相反，后续联调时可能需要把 ++ 和 -- 互换
//                 encoder_delta_R--;
//                 B_LOW_R_count++;
//             } else {
//                 encoder_count_R++;
//                 encoder_delta_R++;
//                 B_HIGH_R_count++;
//             }
//         }
//         last_A_R = current_A_R;
//     }
// }

int32_t Get_Encoder_Speed_L() {
    int32_t speed;

    // [CN] 强行关闭全局中断。防止在我们复制 32 位数据的中途，突然来了一个脉冲把数据改了，导致数据撕裂
    // [EN] Critical Section: Disable interrupts to prevent data tearing when reading 32-bit encoder count
    noInterrupts(); 
    speed = encoder_delta_L; // 提取速度 (积累的脉冲数)
    speed *= ENC_Hz; // 转换为每秒脉冲数 (Hz)
    encoder_delta_L = 0;     // 计数器清零，为下一个周期做准备
    interrupts();            // 恢复全局中断
    speed *= ENCODER_LEFT_DIRECTION; // 考虑编码器方向
    return speed;
}

int32_t Get_Encoder_Speed_R() {
    int32_t speed;
    
    noInterrupts(); 
    speed = encoder_delta_R;
    speed *= ENC_Hz; 
    encoder_delta_R = 0;
    interrupts();
    speed *= ENCODER_RIGHT_DIRECTION; // 考虑编码器方向
    return speed;
}

void Get_Speed (){
    speed_counter++;
    int16_t speed_counter_limit = (200 / ENC_Hz); // [EN] Calculate speed every 50ms / [CN] 每50ms计算一次速度
    if (speed_counter >= speed_counter_limit) {
        speed_counter = 0; 
        int32_t speed_L = Get_Encoder_Speed_L();
        int32_t speed_R = Get_Encoder_Speed_R();
        speed_car = (speed_L + speed_R) / 2; 
        BT_SERIAL.println(speed_car);
    }
}

int32_t Get_Encoder_Tick_L() {
    
    noInterrupts(); 
    encoder_tick_L += encoder_count_L;
    encoder_count_L = 0; // Clear the encoder count after reading
    interrupts();
    return encoder_tick_L;
}

int32_t Get_Encoder_Tick_R() {

    noInterrupts(); 
    encoder_tick_R -= encoder_count_R;
    encoder_count_R = 0; // Clear the encoder count after reading
    interrupts();
    return encoder_tick_R;
}

uint32_t Get_ISR_Count_L(){

    uint32_t temp;

    noInterrupts();
    temp = Isr_L_count;
    interrupts();

    return temp;
}


uint32_t Get_ISR_Count_R(){

    uint32_t temp;

    noInterrupts();
    temp = Isr_R_count;
    interrupts();

    return temp;
}

uint32_t Get_B_HIGH_L_Count() {
    uint32_t temp;

    noInterrupts();
    temp = B_HIGH_L_count;
    interrupts();

    return temp;
}

uint32_t Get_B_LOW_L_Count() {
    uint32_t temp;

    noInterrupts();
    temp = B_LOW_L_count;
    interrupts();

    return temp;
}

uint32_t Get_B_HIGH_R_Count() {
    uint32_t temp;

    noInterrupts();
    temp = B_HIGH_R_count;
    interrupts();

    return temp;
}

uint32_t Get_B_LOW_R_Count() {
    uint32_t temp;

    noInterrupts();
    temp = B_LOW_R_count;
    interrupts();

    return temp;
}

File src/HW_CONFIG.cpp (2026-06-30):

#include "HW_CONFIG.h"

// [EN] Initialize all pins to their SAFE STATES immediately upon boot
// [CN] 在系统启动时，立刻将所有引脚初始化为“绝对安全状态”
void Hardware_Init() {
    // -----------------------------------
    // 1. Configure Pin Directions (输入/输出)
    // -----------------------------------
    pinMode(PIN_MOTOR_L_PWM, OUTPUT);
    pinMode(PIN_MOTOR_L_IN1, OUTPUT);
    pinMode(PIN_MOTOR_L_IN2, OUTPUT);
    
    pinMode(PIN_MOTOR_R_PWM, OUTPUT);
    pinMode(PIN_MOTOR_R_IN1, OUTPUT);
    pinMode(PIN_MOTOR_R_IN2, OUTPUT);
    

    // 编码器引脚设为输入，并开启内部上拉电阻，防止悬空带来高频噪声干扰
    pinMode(PIN_ENC_L_A, INPUT_PULLUP);
    pinMode(PIN_ENC_L_B, INPUT_PULLUP);
    pinMode(PIN_ENC_R_A, INPUT_PULLUP);
    pinMode(PIN_ENC_R_B, INPUT_PULLUP);

    // [致命防御] 锁死电机 PWM 为 0，方向为刹车状态，防止上电疯跑
    analogWrite(PIN_MOTOR_L_PWM, 0);
    digitalWrite(PIN_MOTOR_L_IN1, LOW);
    digitalWrite(PIN_MOTOR_L_IN2, LOW);
    
    analogWrite(PIN_MOTOR_R_PWM, 0);
    digitalWrite(PIN_MOTOR_R_IN1, LOW);
    digitalWrite(PIN_MOTOR_R_IN2, LOW);
}

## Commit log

2026-06-14 promote 2026.6.14
    [BOM_JB_board V1.1_JB_board 主控PCB_2026-06-03.xlsx, JB_balancecar_30六棱铜柱.SLDPRT, JB_balancecar_主框架.SLDPRT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]
2026-07-06 promote encoder
2026-07-19 feat(encoder): implement quadrature encoder driver
    - Add left/right encoder interrupt
    - Add speed calculation
    - Add count accumulation
2026-07-19 FIX Fix PWM polarity inversion caused by optocoupler
    [Encoder.cpp, Motor.cpp, main.cpp]
2026-07-19 excel finished well
    [基于JB_board V1.1的平衡多功能小车的接线手册.xls]
2026-07-24 promote fixing Encoder
2026-07-27 Before implement Timer3
2026-07-28 final commit because of breaken board
